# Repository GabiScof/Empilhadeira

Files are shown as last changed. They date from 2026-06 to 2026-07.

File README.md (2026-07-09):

# Empilhadeira Robótica Autônoma

Projeto da disciplina ENG4061 — Projeto Robótica (PUC-Rio, Turma 3VB).

Empilhadeira em escala reduzida que transporta pallets (~15 cm) em ambiente
controlado (corredor 0,80 × 1,60 m com 6 AprilTags). Dois modos de operação:

- **Manual** — o operador dirige por joystick virtual no celular.
- **Autônomo** — o robô navega sozinho entre AprilTags no mapa, executa missão
  pick-and-place ou estaciona em frente a uma tag (dock-to-tag).

O garfo é sempre manual: tem canal de comando independente nos dois modos e
nunca entra na malha autônoma.

Este README é o ponto de entrada do repositório: resume o que foi feito, como
o sistema funciona e aponta para a documentação detalhada de cada parte
(seção [Mapa da documentação](#mapa-da-documentação)).

---

## Estrutura do repositório

```
Empilhadeira/
├── src/                        Monorepo de software (Pi + ESP32 + frontend + docs)
├── Eletrônica/                 Hardware elétrico: esquemáticos, datasheets, caixas, testes
├── Apresentações_&_Relatório/  PDFs entregues (pré-projeto e entrega final)
├── modelagem_3D/               STLs das peças mecânicas (garfo, polias, eixo, carretel, suporte)
├── images/                     Imagens de apoio (folha de AprilTags tag25h9)
├── APRESENTACAO_SPEC.md        Roteiro técnico da apresentação (visão, controle, comunicação)
└── requirements.txt            Dependências Python fixadas para deploy no Pi
```

---

## Arquitetura

Três camadas hierárquicas, cada uma em um processador e linguagem próprios:

```
┌──────────────────────────────────────────────────────────┐
│  FRONTEND — celular (React + Vite, navegador)             │
│  joystick · D-pad · garfo · missão · mapa · arena · dock  │
└──────────▲──────────────────────────┬─────────────────────┘
     (2) telemetria @20Hz      (1) comando
         WebSocket / Wi-Fi            ▼
┌──────────┴───────────────────────────────────────────────┐
│  RASPBERRY PI — alto nível (Python, FastAPI + asyncio)    │
│  3 loops (Vision · Serial · Control) + WS handler          │
│                                                            │
│  AprilTag → EKF 2D → planejador → executor → setpoint     │
└──────────▲──────────────────────────┬─────────────────────┘
     (4) sensores               (3) setpoint
     UART USB 115200, 20 Hz — JSON + CRC8 + \n
                                      ▼
┌──────────┴───────────────────────────────────────────────┐
│  ESP32 — baixo nível, tempo real (C++/Arduino/PlatformIO) │
│  PID por roda ~100 Hz · encoders · MPU-6050 · PWM → L298n │
└───────────────────────────────────────────────────────────┘
```

Há quatro contratos de dados congelados entre as camadas, espelhados em Python
(Pydantic), C++ (ArduinoJson) e TypeScript. Qualquer mudança de contrato
precisa ser aplicada nas três linguagens.
Detalhes: [`src/docs/serial-protocol.md`](src/docs/serial-protocol.md).

---

## Visão

A câmera USB é o único sensor absoluto. Pipeline:

```
Câmera USB (1280×720) → grayscale → pupil-apriltags (tag25h9, PnP)
  ├─ VisionState (tag mais próxima): detectado, id, z_cm, x_cm, pitch_deg
  └─ TagObservations (todas) → correção do EKF 2D [x, y, θ]
```

**Compensação de tilt:** a câmera fica inclinada 30° para baixo (no topo do
trilho do garfo). `pose.py` rotaciona a pose bruta pelo ângulo de tilt antes
de extrair z/x — converte distância no eixo óptico para distância horizontal.

**Convenções de sinal (validadas na bancada em 2026-07-07):**

- **x negado** na fronteira: no OpenCV, x+ significa tag à direita; na
  convenção do projeto, x+ significa tag à esquerda. Sem essa negação o robô
  se afastaria da tag no hardware (em simulação o problema não aparecia porque
  a visão sintética já usava a convenção do projeto).
- **pitch negado**: a câmera real reporta sinal oposto ao do simulador.
- **Offset câmera→garfo** aplicado em z (−10 cm, lente atrás da ponta do
  garfo) e x, para que z_cm represente a distância da ponta do garfo à tag.

**Multi-tag:** `estimate_vision_state` retorna a tag mais próxima para o
controle reativo; `estimate_tag_observations` retorna todas para o EKF.

**Braço de alavanca lente→eixo:** a pose medida é a da lente, mas o EKF estima
o centro do robô. A correção subtrai `LENS_TO_AXLE_FORWARD_CM` (18 cm) na
direção do heading para evitar viés sistemático.

### Calibração

Procedimento: tabuleiro de xadrez OpenCV. Calibração atual: 2026-07-07,
câmera nova remontada com tilt de 30°, a 1280×720. Intrínsecos:
fx=fy=1023,63 · cx=634,08 · cy=377,08, com coeficientes de distorção
completos (erro de reprojeção não registrado). Uma calibração anterior
(câmera antiga, 640×480, 28 fotos com cantos internos 8×5 e quadrado de
3 cm, reprojeção 0,144 px) foi descartada por valores anômalos.

Regra operacional: a resolução de captura precisa ser a mesma da calibração.
Com `REQUIRE_CAMERA_CALIBRATION=1`, o backend não sobe em modo real sem
calibração válida.

### Visão sintética (SIM=1)

FOV 60°, alcance 3–150 cm, ruído gaussiano ±0,2 cm / ±0,5°, com injeção de
falhas (`tag_hidden`, `vision_blur`, `vision_drop`). Os 9/9 cenários de
aproximação foram validados nessa visão sintética antes de existir robô
físico.

---

## Controle

### Malha em cascata (2 níveis, 2 processadores)

```
Pose alvo (mapa)
   ↓
PathPlanner → [FORWARD 1.2m, TURN 90°, ...]
   ↓
SegmentExecutor — malha EXTERNA no Pi @20 Hz
   pose EKF → (v, ω) → (ω_esq, ω_dir) em rad/s
   ↓ setpoint via serial
PID por roda no ESP32 — malha INTERNA @100 Hz
   ω medido (encoder) → duty PWM → motor
```

O Pi não duplica o PID de roda: a malha externa cuida de posição/heading, a
interna de velocidade. A divisão também é de tempo real — o ESP32 garante
determinismo a 100 Hz; o Pi roda a 20 Hz em Python/asyncio.

### Arbitragem do control loop

O `control_loop.py` roda a 20 Hz e decide qual controlador gera o setpoint:

| Condição | Controlador |
|---|---|
| `MANUAL` | Joystick → cinemática diferencial |
| `AUTOMATICO` + missão ativa | Missão → PathPlanner → SegmentExecutor compartilhado |
| `AUTOMATICO` + dock ligado + sem missão | TagDocker (plano e executor próprios) |
| `AUTOMATICO` + dock desligado + sem missão | NavigationController legado (servo contínuo) |
| `PARADO` / sem comando | Rodas zeradas |

O dock está ligado por default (hardcoded `True` desde 2026-07-07) — o caminho
padrão do AUTOMATICO sem missão é o dock, não o navegador legado.

### Cinemática diferencial

`v = y × MAX_LINEAR_SPEED`, `ω = −x × MAX_ANGULAR_SPEED` (x negado: joystick
x+ = direita, mas ω+ = anti-horário). Velocidades de roda:
`w_esq = (v − ωL/2)/r`, `w_dir = (v + ωL/2)/r`.

### PathPlanner

Se o mapa tem grafo de waypoints: A* sobre o grafo, segmentos TURN/FORWARD
entre waypoints. Se não tem: fallback Manhattan (alinha X, depois Y).
Segmentos menores que 0,5 cm são descartados.

### SegmentExecutor

Malha proporcional sobre a pose do EKF:

- `v = K_DIST × distância` (K=1,5, cap 0,30 m/s)
- `ω = K_HEADING × erro_heading` (K=2,5)
- Tolerância de posição: 2 cm; heading: 4° (folga para o piso de ω não oscilar)
- Forward: se o erro de heading passa de 45°, para e gira primeiro (`v = 0`)
- Timeout por segmento: 45 s → FAULT da missão

**Anti-atrito estático (correção de bancada, 2026-07-07):** perto do alvo, a
malha proporcional comanda velocidades pequenas demais para vencer o atrito
estático — o motor recebe duty mas o robô não anda. Pisos: `v ≥ 0,09 m/s`
(acima da zona de stick-slip) e `|ω| ≥ 1,0 rad/s` (skid-steer precisa de
torque). Teto de giro: `ω ≤ 1,6 rad/s` — acima disso as rodas derrapam, a
odometria conta rotação que não houve e o EKF acumula erro.

### Dock-to-tag

Modo que estaciona o robô em frente a uma única tag por segmentos discretos.
O plano é feito uma vez; a execução usa odometria/EKF. Usa a mesma maquinaria
de navegação da missão (PathPlanner + SegmentExecutor), então serve de ensaio
para a parte de navegação dela (a missão ainda envolve o grafo de waypoints e
a máquina de estados, que o dock não exercita).

**Estados:** `SEEKING` (acumula detecções) → `DOCKING` (executa rota) →
`DONE` / `FAULT`

**Planejamento (Manhattan no frame do robô, não do mapa):**

1. Projeta o alvo no frame do robô: `dz` para frente, `dlat` para o lado.
2. Rota: avança `dz` → gira ±90° → avança `|dlat|` → giro final para alinhar.
   Pernas menores que 1 cm são descartadas.

**Estratégias:** `line_of_sight` (default — usa só z/x, não depende de
convenção de yaw) e `tag_normal` (esquadra com a face da tag; usa a convenção
de yaw com offset π, validada na bancada em 2026-07-07).

**EKF suprimido durante DOCKING:** a `vision_loop` não faz correção por tag
enquanto o dock executa, para evitar salto de pose se a tag não estiver
exatamente na posição declarada no mapa.

**Re-planejamento:** quando DONE, se aparece uma tag que exige deslocamento
maior que 0,10 m, replaneja automaticamente.

### Navegação reativa legada (1 tag)

Controlador servo-contínuo sobre a leitura da câmera. Usado quando o dock está
desligado e não há missão. Quatro fases:

| Fase | Comportamento |
|---|---|
| `COARSE_ALIGN` | Entra quando `|pitch| > 45°`. Gira com ω fixo (±2,0 rad/s), sinal travado na entrada. Sai quando `|pitch| < 35°` (histerese). v=0. |
| `APPROACH` | v proporcional à distância (desaceleração `v_max = √(2·a·d)`); ω por bearing proporcional (longe do centro) ou pitch+x (perto). Heading guard: `|pitch| > 30°` → v=0. FOV guard: reduz v perto da borda do FOV. Centering: reduz v quando `|x| > 1,5 cm`. |
| `FACE` | Perto do Zref e lateralmente alinhado, mas com pitch grande. Gira no lugar com ω ampliado (3× KP_PITCH). |
| `RETREAT` | Marcha-ré a −4 cm/s até z ≥ 30 cm, depois volta a APPROACH. |

Detector de oscilação: 5 ou mais trocas de sinal de ω em 10 amostras →
fallback com `allow_stuck_retreat` (se preso, força ré).

### EKF 2D — [x, y, θ]

Estado em metros/radianos. Predição por odometria diferencial + giroscópio
(fusão 70% gyro / 30% odometria para heading). Correção por observação
absoluta de tag: `H = I`, ruído R escalado pela qualidade da detecção, gate de
Mahalanobis 3,0. Exporta elipse de covariância 95% para a UI.

Nota: as constantes de ruído (`EKF_Q_*`, `EKF_R_*`) existem em `config.py`,
mas não estão conectadas ao `ekf.py` — os valores estão hardcoded na classe.

### Kalman IMU (roll/pitch)

Filtro separado para roll e pitch a partir do acelerômetro e giroscópio (via
filterpy). Saída em graus para a telemetria. Não é usado pelo EKF para
heading — esse vem do giroscópio Z diretamente.

### Auto-calibração do giroscópio

Na partida (robô parado ~2–3 s), o `GyroCalibrator`:

1. Usa a gravidade para descobrir qual eixo do MPU aponta para cima.
2. Determina o sinal do yaw (projeção do gyro no vetor "up" de um sensor destro).
3. Estima o bias de taxa-zero.
4. Rastreia drift térmico lento por EMA (α=0,01) após calibrado.

A posição/orientação física do MPU no chassi não importa — o sensor pode ser
remontado sem alterar código. Guard contra MPU morto: se `|accel| < 2,0 m/s²`
(fisicamente impossível com o sensor funcionando), o frame é descartado.

---

## Missão pick-and-place

```
IDLE → LOAD_MAP → DRAW_TARGETS → GO_TO_PICK → AT_PICK
→ GO_TO_PLACE → AT_PLACE → GO_HOME → DONE   (+ FAULT)
```

- Em `AT_PICK` / `AT_PLACE` o robô para, o operador aciona o garfo e clica
  "continuar" (`POST /mission/continue`).
- Prioridade dos alvos: argumento explícito (UI/curl) > default em config
  (L3/R1) > sorteio com seed 42 (hardcoded na state machine).
- Alvos são `position_id` do mapa (ex.: L3, R1).
- A rota é planejada pelo PathPlanner e executada pelo SegmentExecutor
  compartilhado. Na chegada, `mission.notify_route_done()` avança o estado.
- Timeout de segmento → `mission.fault()`.

API REST: `POST /mission/start`, `/mission/continue`, `/mission/reset`,
`GET /mission/state`.

---

## Máquina de estados e segurança

**Modos:** `MANUAL`, `AUTOMATICO`, `PARADO`

**Latch de segurança:** parada por segurança trava e só `acknowledge()`
destrava. Sem o latch, o loop de 20 Hz re-entraria no modo ativo a cada tick.
Durante missão e dock, o control loop chama `acknowledge()` automaticamente e
alimenta `detectado=True` sintético para suprimir o tag-loss (a tag sai do FOV
em curvas normais de 90°).

**Triggers de parada:**

- Tag perdida por mais de 5 frames em AUTOMATICO
- Command watchdog em MANUAL (400 ms sem comando com rodas em movimento)
- `force_stop()` por perda de serial ou desconexão do WebSocket

### Cadeia de watchdogs (5 vigias em 3 processadores)

| Elo que cai | Limite | Ação |
|---|---|---|
| Celular ↔ Pi (Wi-Fi, MANUAL andando) | 400 ms | PARADO com latch, motivo `command_watchdog` |
| WebSocket fecha | imediato | `force_stop` + comando limpo |
| Tag some em AUTOMATICO | 5 frames (~250 ms) | PARADO com latch (suspenso durante missão/dock) |
| UART sem sensores | 5 ciclos (~250 ms) | `force_stop`, motivo `serial_loss` |
| ESP32 sem setpoint | 200 ms | motores zerados + PID reset (local, independe das camadas acima) |

O watchdog do firmware é a última linha de defesa: roda no ESP32 e não depende
de nada acima dele.

---

## Firmware ESP32

**PID por roda a ~100 Hz:** Kp=20, Ki=5, Kd=1, anti-windup com integral
limitada a ±500. PWM LEDC a 20 kHz, 8 bits (0–255).

**Bypass de setpoint zero (correção de bancada, 2026-07-06):** com um encoder
morto (medida=0), o comando de parar tinha erro 0, mas a integral acumulada
segurava o duty no máximo — o robô ignorava o STOP. Correção: setpoint 0 vira
parada incondicional que bypassa o PID e reseta a integral.

**Encoder x4:** interrupções em CHANGE nas duas fases, tabela de transição de
16 entradas (ISR em IRAM). Transição inválida vale 0, o que rejeita bounce por
construção. 1440 contagens/volta.

**IMU MPU-6050 cru:** acelerômetro ±2g e gyro ±250°/s enviados crus (m/s²,
°/s). Toda a fusão fica no Pi (decisão: firmware simples e determinístico;
filtros ficam onde há ponto flutuante e teste fácil). Auto-recuperação: após
~1 s de leituras mortas, o firmware re-envia o wake (`0x6B`).

**Watchdog local:** 200 ms sem setpoint válido → motores zerados + PID
resetado.

**Garfo:** duty fixo (220); a rosca sem-fim segura a carga parada.
Fins-de-curso previstos no código, mas desabilitados (não montados).

Detalhes: [`src/firmware/README.md`](src/firmware/README.md).

---

## Frontend

Três páginas:

- **Operador** (`/`) — joystick, seletor de modo, D-pad, garfo, dock,
  telemetria, missão, alertas de segurança.
- **Demo** (`/demo`) — arena vista de cima (sim ou real via `/world-state`),
  missão, injeção de falhas, reset de pose, export de debug, seletor de mapa.
- **Mapa** (`/map`) — visualização de mapas JSON com tags, waypoints e grafos.

**D-pad (instrumento de teste):** botões que enviam vetores puros — Frente com
ω exatamente 0 (reta), Gira com v exatamente 0 (giro no lugar), em 30/60/100%
da velocidade. Re-envia a cada 100 ms (heartbeat para o watchdog de 400 ms).
Elimina a variabilidade do joystick nos testes de retidão e odometria.

**Arena:** canvas 2D com grid, tags (pick em vermelho, place em verde), robô
(triângulo azul com cone de FOV), elipse do EKF, trilha executada e rota
planejada (segmentos FORWARD em tracejado).

**WebSocket (reconnect + anti-flapping):** backoff exponencial 500 ms → 10 s.
Guard contra sockets órfãos da dupla montagem do React 18 StrictMode.

### Duas topologias de rede

- **Modo DEV:** frontend no Mac (`npm run dev`, porta 5173); backend no Pi;
  `VITE_PI_WS_URL=ws://<IP_DO_PI>:8000/ws` obrigatório.
- **Modo OPERAÇÃO:** `npm run build` no Mac, `rsync dist/` para o Pi; o
  backend serve o SPA na porta 8000 — sem Node/npm no Pi, uma porta só, e o
  WebSocket resolve sozinho para o host da página.

Detalhes: [`src/frontend/README.md`](src/frontend/README.md).

---

## Simulação (sim-to-real)

Toda a lógica do Pi roda idêntica em `SIM=1` e `SIM=0`. A simulação substitui
duas peças de hardware atrás das mesmas interfaces:

| Componente | Real (`SIM=0`) | Simulado (`SIM=1`) |
|---|---|---|
| Câmera | `RealVisionSource` (OpenCV) | `SimVisionSource` (visão sintética, FOV 60°, ruído) |
| ESP32 | `PySerialTransport` (UART) | `FirmwareEmulator` (PID em Python, motor de 1ª ordem, τ=50 ms) |

As interfaces `VisionSource` e `SerialTransport` garantem que não existe
`if SIM` no código de navegação, controle ou missão.

**Injeção de falhas:** `serial_drop` (ESP32 ignora setpoints), `tag_hidden`
(visão retorna vazio), `wheel_slip` (multiplicadores por roda),
`vision_blur/drop` (probabilidade por frame), `encoder_noise`, `gyro_drift`.

**Mundo simulado:** cinemática diferencial com opção de slip por roda, clamp
na arena, trilha de 2000 pontos.

---

## Problemas encontrados e correções

### Hardware (bancada, 2026-07-06 e 2026-07-07)

1. **Canais dos motores trocados na fiação:** o canal A do L298n acionava a
   roda direita e o B a esquerda — as malhas PID ficaram cruzadas (cada PID
   lia um encoder e acionava a outra roda). Sintoma: uma roda saturava e a
   outra parava, alternando de lado entre testes. Corrigido por remapeamento
   em software. Lição: testar sempre um lado por vez (`--w-esq X --w-dir 0`).

2. **Encoder sobrecontando ~420 pulsos/volta:** estava nos GPIOs 34/35, que
   são input-only e sem pull-up interno — a linha flutuando gerava contagem
   por ruído. Refiado para os GPIOs 23/15 com `INPUT_PULLUP`. Na mesma
   mudança, a decodificação passou de x1 para x4 completa com tabela de
   transição.

3. **Robô ignorava STOP com encoder morto:** a integral acumulada segurava o
   duty no máximo. Correção: setpoint 0 vira parada incondicional que bypassa
   o PID.

4. **MPU-6050 dormindo / barramento I2C caindo:** (a) leituras todas zero com
   temp=36,53 °C indicam sensor dormindo (36,53 é o offset da fórmula de
   temperatura com raw=0); (b) todas zero com temp=0 + erro do Wire indicam
   queda do barramento (contato/EMI perto do L298n). Correções: o firmware
   auto-recupera após ~1 s; o GyroCalibrator descarta frames com
   `|accel| < 2 m/s²`.

5. **Gravação falhando ("chip stopped responding"):** um encoder estava
   alimentado pelo GPIO 2, que é pino de strapping de boot do ESP32.

6. **Ganhos de bancada ≠ chão (assumido):** o atrito estático impede a partida
   com comando baixo; a bateria caindo faz o PID saturar antes.

### Lógica (encontrados em simulação)

- AUTOMATICO congelava após 1 comando (control loop desacoplado do frontend)
- PARADO oscilava sem latch de segurança
- Integral do PID não resetava em PARADO
- ZREF=5 cm causava overshoot (ajustado para 15 cm)
- Perda de tag com offset lateral (bearing guard + histerese)
- Omega bang-bang (substituído por proporcional por bearing)
- FACE durava 1–2 ticks (imposto mínimo de 0,5 s)
- Parada falsa a 24–25 cm (dead zone com histerese)

### Convenções de sinal (fronteira sim↔real)

- Joystick x → ω negado (x+ = direita, ω+ = anti-horário)
- Visão x/pitch negados na fronteira (`pose.py`)
- Dock Manhattan calculado no frame do robô, não do mapa (bug de bancada)
- EKF corrige para o centro do robô (lente→eixo = 18 cm)
- Tilt da câmera 30° + offset z = −10 cm

---

## Decisões de projeto

- Arquitetura hierárquica de 3 camadas: Frontend → Pi → ESP32.
- Pi em Python/FastAPI/asyncio. ESP32 em C++/Arduino/PlatformIO.
- Frontend em React + Vite (navegador do celular).
- Frontend ↔ Pi: WebSocket. Pi ↔ ESP32: UART USB, JSON + CRC8.
- Garfo sempre manual — sem atuação autônoma no protocolo serial.
- Monorepo com três apps (`pi/`, `firmware/`, `frontend/`) + `docs/` + `scripts/`.
- Mapas em JSON — arena paramétrica, não hardcoded.
- PID de roda no ESP32 (100 Hz, C++); malha de posição no Pi (20 Hz, Python).
- Toda a fusão sensorial no Pi (firmware simples e determinístico).
- Simulação atrás de interfaces (`VisionSource`, `SerialTransport`), sem `if SIM`.

---

## Hardware

- Raspberry Pi + câmera USB (1280×720)
- ESP32 DevKit V1
- 2× ponte-H L298n (4 canais: 2 rodas + 1 garfo)
- 2× motor Lego NXT 53787 (rodas) com encoder de quadratura (1440 pulsos/volta, x4)
- Motor JGY-370 12 V com rosca sem-fim (garfo)
- IMU MPU-6050 (I2C)
- Alimentação: 3× 18650 em série (12,6 V) + BMS 3S 40A + regulador LM2596 (5,3 V)
- Arena: corredor 0,80 × 1,60 m com 6 AprilTags (tag25h9, 4 cm)
- Mapa: `corredor_6tags_80x160.json` (tags L1–L3 e R1–R3)

A parte elétrica (bateria, BMS, regulador, drivers, esquemáticos, datasheets,
caixas dos eletrônicos) está documentada em
[`Eletrônica/README.md`](Eletrônica/README.md).

---

## Mecânica

A estrutura mecânica da empilhadeira foi desenvolvida com um sistema de elevação baseado em **polia com corda**. Nesse mecanismo, o motor aciona o carretel, que enrola ou desenrola a corda responsável por movimentar o garfo verticalmente. A polia foi utilizada para guiar a corda e permitir que o movimento de subida e descida ocorresse de forma mais controlada.

Além dos componentes comerciais, também foi feita uma **modelagem 3D própria**, armazenada na pasta [`modelagem_3D/`](modelagem_3D/). Essa pasta contém os arquivos STL das peças mecânicas utilizadas no projeto, incluindo:

- `Carretel.stl`
- `Eixo.stl`
- `Garfo.stl`
- `Polia Direita.stl`
- `Polia Esquerda.stl`
- `Suporte.stl`

Na montagem mecânica, foram utilizados os seguintes materiais principais:

- Hastes metálicas de 8 mm de diâmetro;
- Rolamentos lineares LM8UU;
- Polia com rolamento interno de 5 mm de diâmetro;
- Motor worm gear para acionamento do garfo.

A escolha do motor com rosca sem-fim foi importante porque ele permite maior redução de velocidade e ajuda a manter o garfo parado quando o motor não está sendo acionado, evitando que a carga desça sozinha. Dessa forma, a solução mecânica combina peças impressas em 3D, componentes metálicos de guiamento e um sistema simples de polia e corda para realizar o movimento vertical do garfo.

O modelo 3D também pode ser acessado pelo
[Onshape](https://cad.onshape.com/documents/f90b50a5cbad31499728b9c2/w/215a010849009c6ab330cfee/e/5a6f6cd27785eeb6a40e91f8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).

---

## Quick start

### Simulação (sem hardware)

```bash
cd src
python3 -m venv .venv && source .venv/bin/activate
pip install -e ".[dev]"

SIM=1 ./scripts/run_pi.sh           # backend em http://localhost:8000

cd frontend && npm install && npm run dev   # http://localhost:5173/demo
```

### Testes

```bash
python3 -m pytest pi/tests/ -v              # backend (210 testes)
cd frontend && npx vitest run               # frontend (11 testes)
python3 pi/tests/sim_sweep.py               # 9 cenários de aproximação
```

### Deploy no robô real

1. Copie `src/.env.example` para `src/.env` e configure `SIM=0`, a porta
   serial e a câmera.
2. No Pi: `pip install -e .` e `./scripts/run_pi.sh`
3. Frontend (modo operação): `npm run build` no Mac e copie `frontend/dist/`
   para o Pi — o backend serve o SPA em `http://<IP_DO_PI>:8000/`

Guia completo: [`src/docs/hardware-deployment.md`](src/docs/hardware-deployment.md)

---

## Números de referência

| Item | Valor |
|---|---|
| Arena | corredor 0,80 × 1,60 m, 6 tags (L1–L3, R1–R3) |
| AprilTag | família tag25h9, 4 cm |
| Câmera | USB, 1280×720; fx=fy=1023,6 · cx=634,1 · cy=377,1 (calibração 2026-07-07) |
| Tilt da câmera | 30° para baixo; offset z = −10 cm (lente→garfo); lente→eixo = 18 cm |
| Loops do Pi | 3 no startup (Vision · Serial · Control, 20 Hz cada); Telemetria via WS handler por conexão |
| PID firmware | 100 Hz, Kp=20 Ki=5 Kd=1, anti-windup ±500, PWM 20 kHz 8 bits |
| Encoders | quadratura x4, 1440 pulsos/volta |
| EKF | estado [x,y,θ]; heading 70% gyro + 30% odom; gate Mahalanobis 3,0 |
| SegmentExecutor | K_DIST=1,5 · K_HEADING=2,5 · tol. posição 2 cm · tol. heading 4° |
| Anti-atrito | v ≥ 0,09 m/s · \|ω\| ≥ 1,0 rad/s · ω_turn ≤ 1,6 rad/s |
| Serial | UART USB 115200 baud, 20 Hz, JSON + CRC-8/MAXIM + `\n` |
| Watchdogs | comando 400 ms · serial 250 ms · firmware 200 ms · tag-loss 250 ms |
| v_máx medida | 24 cm/s (100 cm em 4,16 s) → config 19 cm/s (80%, folga para PID + bateria) |
| Geometria | roda r=2,7 cm · entre-eixos 15 cm · standoff 15 cm |
| Missão | IDLE→LOAD_MAP→DRAW_TARGETS→GO_TO_PICK→AT_PICK→GO_TO_PLACE→AT_PLACE→GO_HOME→DONE (+FAULT) |

---

## Estrutura do monorepo `src/`

```
src/
├── pi/                    Backend Python (FastAPI + asyncio)
│   ├── app/
│   │   ├── control/       EKF, navegação, planejador, executor, Kalman, dock-to-tag
│   │   ├── mission/       Máquina de estados pick-and-place
│   │   ├── tasks/         3 loops asyncio (visão, serial, controle) + WS handler
│   │   ├── comms/         Protocolo serial (CRC8, framing, transporte)
│   │   ├── vision/        Detector AprilTag, calibração, pose (tilt, offsets)
│   │   ├── hardware/      Interfaces VisionSource / SerialTransport
│   │   ├── sim/           Emulador de firmware, visão sintética, falhas, mundo
│   │   ├── world/         Modelo de mundo, mapas (JSON/Pydantic), robô
│   │   ├── telemetry/     Agregador de telemetria
│   │   ├── config.py      Parâmetros centralizados
│   │   ├── models.py      4 contratos Pydantic
│   │   ├── state.py       Estado compartilhado (lock asyncio)
│   │   └── main.py        Ponto de entrada + rotas REST
│   ├── maps/              Mapas JSON da arena
│   ├── calibracao/        Intrínsecos da câmera (JSON)
│   └── tests/             210 testes pytest
├── firmware/              ESP32 (C++/PlatformIO)
│   └── src/               main, pid, motors, encoders, protocol, config
├── frontend/              React + Vite + Tailwind
│   └── src/
│       ├── pages/         Operador (/), Demo (/demo), Mapa (/map)
│       ├── components/    Joystick, DPad, Arena, Telemetria, Missão, Dock, etc.
│       ├── ws/            useWebSocket (reconnect, anti-flapping)
│       └── types/         contracts.ts (espelho TypeScript)
├── docs/                  Documentação técnica
└── scripts/               Scripts de operação e teste
```

---

## Mapa da documentação

### Ponto de entrada por app

| Documento | Conteúdo |
|---|---|
| [`src/README.md`](src/README.md) | Visão geral do monorepo de software, como rodar e testar |
| [`src/pi/README.md`](src/pi/README.md) | Backend do Raspberry Pi |
| [`src/firmware/README.md`](src/firmware/README.md) | Firmware do ESP32 |
| [`src/frontend/README.md`](src/frontend/README.md) | Frontend React |
| [`Eletrônica/README.md`](Eletrônica/README.md) | Bateria, BMS, regulador, motores, drivers, sensores |

### Conceito e arquitetura

| Documento | Conteúdo |
|---|---|
| [`src/docs/architecture.md`](src/docs/architecture.md) | Arquitetura de 3 camadas, EKF, decisões, parâmetros em aberto |
| [`src/docs/serial-protocol.md`](src/docs/serial-protocol.md) | Os 4 contratos de comunicação (fonte de verdade) |
| [`src/docs/navigation.md`](src/docs/navigation.md) | Planejador, executor, malha em cascata |
| [`src/docs/mission.md`](src/docs/mission.md) | Missão pick-and-place, API REST, garra manual |
| [`src/docs/dock-to-tag.md`](src/docs/dock-to-tag.md) | Aproximação por segmentos a uma tag |
| [`src/docs/maps.md`](src/docs/maps.md) | Formato JSON dos mapas da arena |
| [`src/docs/simulation.md`](src/docs/simulation.md) | Modo SIM=1, injeção de falhas, endpoints `/sim/*` |

### Hardware e operação

| Documento | Conteúdo |
|---|---|
| [`src/docs/hardware-bring-up.md`](src/docs/hardware-bring-up.md) | Pinos, energia, montagem, calibração |
| [`src/docs/hardware-deployment.md`](src/docs/hardware-deployment.md) | Deploy no robô real, passo a passo |
| [`src/docs/hardware-interfaces.md`](src/docs/hardware-interfaces.md) | Interfaces `VisionSource` / `SerialTransport` (SIM↔real) |
| [`src/docs/camera-calibration.md`](src/docs/camera-calibration.md) | Calibração da câmera (xadrez OpenCV) |

### Testes e status

| Documento | Conteúdo |
|---|---|
| [`src/docs/real-robot-test-plan.md`](src/docs/real-robot-test-plan.md) | Plano de testes no hardware em 3 fases |
| [`src/docs/readiness-sim-to-real.md`](src/docs/readiness-sim-to-real.md) | Auditoria de prontidão SIM→real |
| [`src/docs/simulator-to-real.md`](src/docs/simulator-to-real.md) | O que a simulação provou e o que não provou |
| [`src/docs/verification-status.md`](src/docs/verification-status.md) | Testes passando, bugs corrigidos |

### Apresentação e relatórios

| Documento | Conteúdo |
|---|---|
| [`APRESENTACAO_SPEC.md`](APRESENTACAO_SPEC.md) | Roteiro técnico da apresentação (visão, controle, comunicação) |
| `Apresentações_&_Relatório/` | PDFs entregues: relatório pré-projeto, entrega de pré-projeto e entrega final |

---

## Verificação

| Teste | Resultado |
|---|---|
| pytest (backend Pi) | 210 testes — 209 passam, 1 pulado |
| vitest (frontend) | 11/11 passam |
| sim_sweep (9 cenários de aproximação) | 9/9 convergem (parada a 15,0–16,3 cm; offset lateral ≤ 2,4 cm; heading ≤ 3,7°) |
| full_trace (13 cenários) | 12/13 (1 LOST esperado — tag fora do FOV) |
| Bancada 2026-07-07 | encoders x4, motores/sentido, PID, watchdog < 200 ms, CRC e MPU validados |
| Câmera | recalibrada em 2026-07-07 (1280×720, câmera nova) |
| v_máx no chão | cronometrada: 100 cm em 4,16 s = 24 cm/s → config 19 cm/s |

## Status

| Item | Estado |
|---|---|
| Lógica + simulação | Validado (210 pytest + 9/9 sim_sweep) |
| Firmware ESP32 | Gravado e exercitado na bancada (2026-07-06/07) |
| Backend Pi (câmera + serial) | Implementado |
| Calibração da câmera + mapa real | Feito |
| Bancada (encoders, motores, PID, watchdogs) | Validado |
| Dock-to-tag | Implementado, aprovado em teste de unidade |
| Modo operação (Pi serve o frontend) | Funcionando |
| Fase 2 — manual no chão | Pendente |
| Fase 3 — autonomia no chão | Pendente |

## Tech stack

| Camada | Stack |
|---|---|
| Pi | Python 3.11+ · FastAPI · asyncio · OpenCV · pupil-apriltags · filterpy · Pydantic · pyserial-asyncio |
| ESP32 | C++ · Arduino · PlatformIO · ArduinoJson |
| Frontend | React 18 · Vite · Tailwind CSS |

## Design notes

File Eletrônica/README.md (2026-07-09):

# Eletrônica — Empilhadeira Robótica Autônoma

> Extraído do Relatório Pré-Projeto — ENG4061 Projeto Robótica (PUC-Rio, Turma 3VB)

Esta seção documenta a alimentação, o regulador de tensão, os motores/drivers, os
microcontroladores e os sensores utilizados no projeto, além do fluxo geral de
energia e informação do sistema.

---

## Sumário

- [2.1 Bateria e BMS](#21-bateria-e-bms)
- [2.2 Regulador de tensão](#22-regulador-de-tensão)
- [2.3 Motores e drivers](#23-motores-e-drivers)
- [2.4 Microcontroladores](#24-microcontroladores)
- [2.5 Sensores](#25-sensores)
- [2.6 Fluxo do projeto](#26-fluxo-do-projeto)
- [Resumo de componentes](#resumo-de-componentes)
- [Conteúdo da pasta](#conteúdo-da-pasta)

---

## 2.1 Bateria e BMS

O sistema é alimentado por 3 baterias 18650 de íon-lítio em série, cada uma com 4,2 V,
totalizando uma tensão nominal de **12,6 V**. Essa tensão supre motores, microcontroladores e
sensores. As baterias de íon-lítio foram escolhidas pela facilidade de uso, portabilidade e
disponibilidade em laboratório — exigindo atenção ao controle de temperatura, já que são
inflamáveis em condições extremas.

Para gerenciar as baterias com segurança, é utilizado um **BMS (Battery Management System)**,
responsável por:
- Controlar temperatura, carga e descarga das baterias
- Balancear a carga entre as células
- Verificar estado de vida e estado de carga
- (Em versões mais avançadas) transmitir dados das baterias para processamento posterior

**Opção adotada:** BMS 3S 40A — escolhido como opção conservadora frente aos picos de corrente
estimados dos motores sob carga (consumo estimado do sistema entre 10–15 A dependendo do modo
de operação).

---

## 2.2 Regulador de tensão

Como a alimentação de 12,6 V das baterias é inconsistente para os demais componentes, é
utilizado um único regulador de tensão para estabilizar a alimentação e proteger componentes
sensíveis:

| Regulador | Função | Tensão de saída |
|---|---|---|
| **LM2596** | Alimenta todos os periféricos (Raspberry Pi, ESP32, sensores, câmera) | 12V → 5,3V |

> Um único regulador é suficiente porque todos os demais componentes (Raspberry Pi, ESP32,
sensores, câmera) já possuem reguladores de tensão internos próprios, que ajustam os 5,3V de
entrada para o nível exigido por cada um, evitando que queimem.

---

## 2.3 Motores e drivers

| Motor | Uso | Características |
|---|---|---|
| **Lego NXT (id 53787)** | Movimentação (tração) | Torque de 16,7 N·cm · 117 RPM · encoder integrado · controle via PWM (ESP32) |
| **JGY-370-12V (Worm Gear)** | Garfo mecânico (elevação) | Motor DC com caixa de redução sem-fim; dificulta *backdrive* (sustenta carga passivamente quando desenergizado) |

**Driver:** 2× `L298N` (ponte H dupla) — controlam os três motores: um módulo aciona os
dois motores de tração e o outro o motor do garfo, com controle de sentido e PWM por canal.

---

## 2.4 Microcontroladores

O projeto utiliza dois microcontroladores em uma arquitetura hierárquica:

- **Raspberry Pi** — controle de alto nível: processamento das AprilTags (visão computacional),
máquina de estados de movimentação, lei de navegação autônoma e agregação de telemetria.
- **ESP32** — controle de baixo nível: geração de PWM, malhas fechadas locais (PID) dos motores,
leitura de sensores embarcados (MPU-6050, encoders) e comunicação serial com o Raspberry Pi.

> O ESP32 foi escolhido por sua facilidade em controlar motores com precisão em tempo real —
algo que o Raspberry Pi, rodando um SO Linux convencional, não garante nativamente.

---

## 2.5 Sensores

- **MPU-6050** — acelerômetro + giroscópio (a temperatura integrada não entra na fusão;
viaja na telemetria e serve para diagnóstico do sensor). Os dados são lidos pelo ESP32 via
I²C e enviados crus ao Raspberry Pi, onde um **filtro de Kalman** estima roll/pitch e o
giroscópio Z entra direto na fusão de heading do EKF.
- **Encoders integrados** (motor Lego) — usados para calcular RPM e realimentar a malha PID de
controle de velocidade.
- **Câmera** — utilizada para detecção de AprilTags via visão computacional (OpenCV + pupil-apriltags).

---

## 2.6 Fluxo do projeto

A eletrônica funciona como um fluxo contínuo de energia e informação:

1. A energia das baterias é condicionada e dividida em dois caminhos: um direto aos motores, e
outro regulado (LM2596, 5,3V) para os microcontroladores/sensores.
2. Sensores e encoders alimentam o ESP32, que repassa os dados ao Raspberry Pi via serial (UART).
3. O Raspberry Pi processa a informação (visão computacional + telemetria) e retorna *setpoints*
ao ESP32.
4. O ESP32 converte os *setpoints* em movimento físico nos motores.
5. O Raspberry Pi transmite os dados consolidados ao dispositivo do operador (frontend), que
pode enviar novos comandos, fechando o ciclo.

```
Baterias (12,6V) ──┬──► Motores (tração + garfo)
                    └──► Regulador LM2596 (5,3V) ──► RPi / ESP32 / Sensores / Câmera

Sensores/Encoders ──► ESP32 ──UART──► Raspberry Pi ──WebSocket──► Frontend (operador)
                       ▲                                              │
                       └──────────────── comandos/setpoints ──────────┘
```

---

## Resumo de componentes

| Categoria | Componente | Observação |
|---|---|---|
| Fonte | 3× baterias 18650 (íon-lítio) | Série · 12,6 V nominal |
| Proteção | BMS 3S 40A | Balanceamento e proteção de carga/descarga |
| Regulador | LM2596 | 12V → 5,3V (único, alimenta todos os periféricos) |
| Driver | 2× L298N (Ponte H dupla) | Um módulo para os 2 motores de tração, outro para o garfo |
| Motor | Lego NXT 53787 ×2 | Tração |
| Motor | JGY-370-12V (Worm Gear) | Garfo mecânico |
| Microcontrolador | Raspberry Pi | Alto nível — visão computacional, navegação, telemetria |
| Microcontrolador | ESP32 | Baixo nível — PWM, PID, leitura de sensores |
| Sensor | MPU-6050 | IMU (acelerômetro + giroscópio; termômetro só para diagnóstico) |
| Sensor | Câmera | Detecção de AprilTags |

---

## Conteúdo da pasta

| Item | Descrição |
|---|---|
| `Circuito_elétrico_final.pdf` / `Circuito_elétrico_V1.pdf` | Esquemas elétricos (versão final e V1) |
| `Esquemática_elétrica/` | Projeto KiCad do esquema elétrico |
| `Datasheets/` | Datasheets dos componentes (ESP32, L298, LM2596, MPU-6000/6050, AMS1117, MP2307) |
| `Caixa_eletrônicos/` | Caixas dos eletrônicos — V1 e V2 (STEP/Parasolid + fotos) |
| `Testes_eletronica.ino` | Sketch de referência dos testes de bancada da eletrônica |
| `Fotos_Vídeos/` | Fotos e vídeos da montagem |
| `Calculo de corrente.txt` / `Lista de Compras.txt` | Dimensionamento de corrente e lista de compras |

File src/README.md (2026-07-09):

# Empilhadeira Robótica Autônoma

Empilhadeira em escala reduzida com navegação autônoma por AprilTag, missão
pick-and-place e telemetria em tempo real.

> Estado atual: lógica implementada e validada em simulação (`SIM=1`).
> Pronta para bring-up no hardware real — ver
> [`docs/hardware-deployment.md`](docs/hardware-deployment.md).

## Arquitetura — 3 camadas

```
┌──────────────────────────────────────────────────────┐
│  Frontend (celular) — React + Vite                    │
│  joystick · telemetria · missão · mapa · garfo        │
└───────────────▲──────────────────────┬────────────────┘
        (2) telemetria @20Hz    (1) comando
            WebSocket / Wi-Fi          ▼
┌───────────────┴────────────────────────────────────────┐
│  Raspberry Pi — Python (FastAPI + asyncio)              │
│  Vision · Serial · Control Loop (3 loops no startup)   │
│  + WebSocket handler por conexão                       │
│  EKF 2D · planejador · missão · dock · nav legada     │
└───────────────▲──────────────────────┬─────────────────┘
        (4) sensores            (3) setpoint
        UART USB 115200, 20 Hz · JSON+CRC8+\n
                                       ▼
┌───────────────┴─────────────────────────────────────────┐
│  ESP32 — C++ (Arduino, PlatformIO)                       │
│  PID por roda ~100 Hz · encoders · MPU · PWM → L298n    │
└─────────────────────────────────────────────────────────┘
```

Detalhes em [`docs/architecture.md`](docs/architecture.md).

## Apps

| Pasta | Camada | README |
|---|---|---|
| [`pi/`](pi/) | Raspberry Pi (Python) | [pi/README.md](pi/README.md) |
| [`firmware/`](firmware/) | ESP32 (C++) | [firmware/README.md](firmware/README.md) |
| [`frontend/`](frontend/) | Celular (React) | [frontend/README.md](frontend/README.md) |

## Como rodar

```bash
# Instalar
python3 -m venv .venv && source .venv/bin/activate
pip install -e ".[dev]"
cp .env.example .env   # ajustar conforme ambiente (nota: MAP= no .env NÃO tem efeito; mapa padrão é hardcoded)

# Simulação (sem hardware)
SIM=1 ./scripts/run_pi.sh

# Hardware real
SIM=0 ./scripts/run_pi.sh

# Frontend
cd frontend && npm install && npm run dev

# Testes completos
python3 -m pytest pi/tests/ -v
bash scripts/verify.sh
```

> O pacote `app` vive em `pi/app`. O script `run_pi.sh` já roda de dentro de `pi/`.
> Alternativa manual: `SIM=1 uvicorn app.main:create_app --factory --app-dir pi`.

## Documentação

| Documento | Conteúdo |
|---|---|
| [readiness-sim-to-real.md](docs/readiness-sim-to-real.md) | Auditoria sim→real — Pi, ESP, filtros, interfaces, bloqueantes |
| [simulator-to-real.md](docs/simulator-to-real.md) | O que a simulação cobre e o que transferimos |
| [hardware-deployment.md](docs/hardware-deployment.md) | Passo a passo no robô real |
| [verification-status.md](docs/verification-status.md) | Testes passando, bugs corrigidos, sim_sweep |
| [hardware-interfaces.md](docs/hardware-interfaces.md) | Encaixes SIM↔real (`VisionSource`, `SerialTransport`) |
| [hardware-bring-up.md](docs/hardware-bring-up.md) | Pinos, energia, fiação, calibração |
| [serial-protocol.md](docs/serial-protocol.md) | Contratos serial (4 mensagens) |
| [architecture.md](docs/architecture.md) | Decisões, parâmetros em aberto |
| [navigation.md](docs/navigation.md) | Planejador, executor, APPROACH/FACE/RETREAT |
| [mission.md](docs/mission.md) | Missão pick-and-place |
| [dock-to-tag.md](docs/dock-to-tag.md) | Aproximação por segmentos a 1 tag (`DOCK_TO_TAG_ENABLED`, ligado por default) |
| [maps.md](docs/maps.md) | Formato JSON dos mapas |
| [simulation.md](docs/simulation.md) | Modo SIM=1, falhas, APIs `/sim/*` |
| [camera-calibration.md](docs/camera-calibration.md) | Calibração xadrez |

## Verificação (2026-07-08)

| Check | Resultado |
|---|---|
| pytest | 210 testes (209 passam, 1 pulado) |
| frontend vitest | 11/11 |
| sim_sweep | 9/9 convergem |
| full_trace | 12/13 (1 LOST esperado — FOV) |

## Parâmetros em aberto

Valores provisórios em `pi/app/config.py` e `firmware/src/config.h`, marcados
`TODO(equipe)`. Lista completa em
[`docs/architecture.md#parâmetros-em-aberto`](docs/architecture.md#parâmetros-em-aberto)
e checklist de medição em [`docs/hardware-deployment.md`](docs/hardware-deployment.md).

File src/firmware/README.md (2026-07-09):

# Firmware ESP32 — Empilhadeira Robótica

Controle de baixo nível em tempo real: PID por roda, acionamento PWM/L298n, leitura de
encoders por interrupção, MPU-6050, garfo com fim-de-curso e protocolo serial JSON+CRC8.

## Sumário

1. [Arquitetura do Firmware](#1-arquitetura-do-firmware)
2. [Mapa de Pinos (GPIO)](#2-mapa-de-pinos-gpio)
3. [Fiação Detalhada](#3-fiação-detalhada)
4. [Constantes e Calibração](#4-constantes-e-calibração)
5. [Comportamento Esperado](#5-comportamento-esperado)
6. [Como Compilar e Gravar](#6-como-compilar-e-gravar)
7. [Procedimentos de Teste](#7-procedimentos-de-teste)
8. [Troubleshooting](#8-troubleshooting)
9. [Decisões Pendentes (TODO)](#9-decisões-pendentes-todo)

---

## 1. Arquitetura do Firmware

```
┌──────────────────────────────────────────────────────┐
│                    loop()                             │
│                                                      │
│  ┌─────────────────────┐  ┌────────────────────────┐ │
│  │  Serial RX (contínuo)│  │ Watchdog (200 ms)      │ │
│  │  SetpointFrameDecoder│  │ → motorsStop() se cair │ │
│  └─────────┬───────────┘  └───────────┬────────────┘ │
│            │                          │              │
│  ┌─────────▼──────────────────────────▼──────────┐   │
│  │  PID Loop ~100 Hz (cada 10 ms)                │   │
│  │  1. encoderReadEsq/Dir(dt) → ω medido         │   │
│  │  2. pid.update(medido, dt) → esforço u        │   │
│  │  3. motorSetWheel(u) → PWM/L298n              │   │
│  │  4. motorSetFork(cmd) → com fim-de-curso      │   │
│  └───────────────────────────────────────────────┘   │
│                                                      │
│  ┌───────────────────────────────────────────────┐   │
│  │  Serial TX ~20 Hz (cada 50 ms)                │   │
│  │  1. readMpu(sensors) → I2C burst read 14B     │   │
│  │  2. encodeSensors() → JSON+CRC8+\n            │   │
│  │  3. Serial.write(frame)                       │   │
│  └───────────────────────────────────────────────┘   │
└──────────────────────────────────────────────────────┘
```

- **Dual-cadence non-blocking**: `millis()` controla os intervalos, sem `delay()`.
- **PID por roda**: Kp + Ki + Kd com anti-windup (clamping integral a ±500).
- **Watchdog de setpoint**: 200 ms sem mensagem do Pi → motores zerados.
- **Garfo com fim-de-curso**: corte local instantâneo (~100 Hz), sem depender do Pi.

---

## 2. Mapa de Pinos (GPIO)

### Tabela completa

Alinhado 1:1 com `Testes_eletronica.ino` (fonte da verdade da placa real).
Os nomes entre colchetes são os defines equivalentes naquele firmware de teste.

| Função | GPIO | Dir | Destino no Hardware | Observação |
|---|---|---|---|---|
| Motor Esq IN1 | 27 | OUTPUT  | L298n #1 IN3 (canal B) | [era M3_IN1] canais trocados na fiação — ver nota abaixo |
| Motor Esq IN2 | 26 | OUTPUT  | L298n #1 IN4 (canal B) | [era M3_IN2] |
| Motor Esq PWM | 25 | OUTPUT  | L298n #1 ENB (canal B) | [era M3_EN] LEDC ch0, 20 kHz, 8 bits |
| Motor Dir IN1 | 12 | OUTPUT  | L298n #1 IN1 (canal A) | [era M2_IN1] strapping — LOW no boot, sem pull-up externo |
| Motor Dir IN2 | 14 | OUTPUT  | L298n #1 IN2 (canal A) | [era M2_IN2] |
| Motor Dir PWM | 13 | OUTPUT  | L298n #1 ENA (canal A) | [era M2_EN] LEDC ch1, 20 kHz, 8 bits |
| Fork IN1 | 18 | OUTPUT  | L298n #2 IN1 | [M1_IN1] |
| Fork IN2 | 19 | OUTPUT  | L298n #2 IN2 | [M1_IN2] |
| Fork PWM | 5 | OUTPUT  | L298n #2 ENA | [M1_EN] LEDC ch2, 20 kHz, 8 bits |
| Encoder Esq A | 23 | INPUT↑  | NXT 53787 encoder fase A | Interrupção CHANGE (x4) — refiado 2026-07-06 (era 34) |
| Encoder Esq B | 15 | INPUT↑  | NXT 53787 encoder fase B | Interrupção CHANGE (x4) — refiado 2026-07-06 (era 35); strapping (MTDO), ver §2 |
| Encoder Dir A | 32 | INPUT↑  | NXT 53787 encoder fase A | [ENC1_A] Interrupção CHANGE (x4) |
| Encoder Dir B | 33 | INPUT↑  | NXT 53787 encoder fase B | [ENC1_B] Interrupção CHANGE (x4) |
| Fork Limit Top | -1 | — | (chave não montada) | Desabilitado — nunca bloqueia |
| Fork Limit Bottom | -1 | — | (chave não montada) | Desabilitado — nunca bloqueia |
| Enc Power VCC | 2 | OUTPUT  | Encoder "VCC" (3,3 V pelo GPIO) | `PIN_ENC_POWER_VCC` — `encodersBegin()` seta HIGH; limite ~40 mA/GPIO |
| Enc Power GND | 4 | OUTPUT  | Encoder GND | `PIN_ENC_POWER_GND` — `encodersBegin()` seta LOW |
| I2C SDA | 21 | I2C | MPU-6050 SDA | Padrão ESP32 |
| I2C SCL | 22 | I2C | MPU-6050 SCL | Padrão ESP32 |

> **Canais dos motores (conferido na bancada 2026-07-06):** na fiação real o
> canal A do L298n (12/14/13) aciona a roda direita e o canal B (27/26/25)
> a esquerda — o inverso do rótulo M2/M3 do `Testes_eletronica.ino`.
> Remapeado por software no `config.h` (`PIN_MOTOR_ESQ_*`=27/26/25 com
> `MOTOR_ESQ_INV=false`; `PIN_MOTOR_DIR_*`=12/14/13 com `MOTOR_DIR_INV=true`),
> validado com `bench_setpoint` um lado por vez.

`INPUT↑` = INPUT_PULLUP (resistor interno de ~45 kΩ). Todos os pinos de
encoder atuais (23/15 e 32/33) têm pull-up interno — nenhum pull-up externo
é necessário. (Refiado 2026-07-06: o encoder esquerdo estava em 34/35,
input-only e sem pull-up interno, e sobrecontava ~420 pulsos/volta por ruído
nas bordas; foi movido para 23/15.)

### GPIOs com cuidado especial

| GPIO | Motivo |
|---|---|
| 0 | Strapping pin (flash mode se LOW no boot) — não usado |
| 2 | Strapping pin. Usado como "VCC" do encoder (`PIN_ENC_POWER_VCC`, OUTPUT HIGH) e aciona o LED onboard (acende junto — normal). Na gravação precisa estar LOW/solto; a carga do encoder normalmente puxa para baixo — se a gravação falhar, desconectar o fio do GPIO 2 |
| 6-11 | Conectados ao flash SPI interno — nunca usar |
| 12 | Strapping (tensão do flash). Usado como DIR IN1 (canal A; era rotulado ESQ até 2026-07-06) — funciona porque IN1 idle=LOW; não adicionar pull-up externo |
| 15 | Strapping (MTDO). Usado como Encoder Esq B — se LOW no boot, apenas silencia as mensagens de boot da ROM; inofensivo |
| 34-39 | Input-only sem pull-up interno. 34/35 estão livres (refiado 2026-07-06 — o encoder esquerdo saiu deles); se reutilizar, lembrar do pull-up externo |

---

## 3. Fiação Detalhada

### 3.1 L298n #1 (rodas)

```
ESP32 GPIO 12 ──── L298n IN1 (canal A)   ← strapping: sem pull-up externo
ESP32 GPIO 14 ──── L298n IN2 (canal A)
ESP32 GPIO 13 ──── L298n ENA (canal A)   ← remover jumper ENA
ESP32 GPIO 27 ──── L298n IN3 (canal B)
ESP32 GPIO 26 ──── L298n IN4 (canal B)
ESP32 GPIO 25 ──── L298n ENB (canal B)   ← remover jumper ENB

L298n VCC (12V)  ── Fonte 12V
L298n GND        ── GND comum (ESP32 + fonte)
L298n 5V out     ── não usar para alimentar ESP32 (usar USB ou reg. externo)

Motor Dir (+/-) ─── L298n OUT1/OUT2 (canal A)
Motor Esq (+/-) ─── L298n OUT3/OUT4 (canal B)
```

> **Conferido na bancada 2026-07-06:** o canal A aciona a roda direita e o
> canal B a esquerda (fiação real, inverso do rótulo M2/M3). O `config.h` já
> remapeia por software — não trocar fios sem atualizar o mapa de pinos.

Remover os jumpers de ENA e ENB do módulo L298n. Esses jumpers forçam 5V
constante no enable, desabilitando o controle PWM. Com o jumper removido,
o pino ENA/ENB fica livre para receber o sinal PWM do ESP32.

### 3.2 L298n #2 (garfo)

```
ESP32 GPIO 18 ──── L298n #2 IN1
ESP32 GPIO 19 ──── L298n #2 IN2
ESP32 GPIO  5 ──── L298n #2 ENA          ← remover jumper ENA

Motor Garfo (+/-) ── L298n #2 OUT1/OUT2
```

Alternativa: driver menor (L9110S, TB6612) se o garfo precisar de menos corrente.

### 3.3 Encoders (Lego NXT 53787)

```
Motor NXT (conector 6 pinos):
  Pin 1 (branco) ─── 5V (ou 3.3V — verificar)
  Pin 2 (preto)  ─── GND
  Pin 5 (amarelo)─── ESP32 GPIO 23 (Esq A) / GPIO 32 (Dir A)
  Pin 6 (azul)   ─── ESP32 GPIO 15 (Esq B) / GPIO 33 (Dir B)
```

> **Refiado 2026-07-06**: o encoder esquerdo estava em GPIO 34/35 (input-only,
> sem pull-up interno) e sobrecontava por ruído nas bordas. Foi movido para
> 23/15, que têm pull-up interno — o `INPUT_PULLUP` do `encoders.cpp` vale e
> nenhum pull-up externo é necessário. GPIO 34/35 ficaram livres.

> **Nota**: o encoder do NXT opera a 5V pela especificação original. Se o sinal
> de saída for 5V (push-pull), pode ser necessário um divisor resistivo
> (1k + 2k) ou level shifter para proteger o ESP32 (máximo 3.3V nos GPIOs).
> Verificar com multímetro antes de conectar.

### 3.4 MPU-6050

```
MPU VCC ─── 3.3V do ESP32
MPU GND ─── GND
MPU SDA ─── ESP32 GPIO 21
MPU SCL ─── ESP32 GPIO 22
MPU AD0 ─── GND (endereço 0x68)
```

### 3.5 Fim-de-curso do garfo

Estado atual: desabilitado (`PIN_FORK_LIMIT_TOP/BOTTOM = -1` em `config.h`).
As chaves não estão montadas no robô. `motors.cpp` pula o `pinMode` e
`forkAtTopLimit()`/`forkAtBottomLimit()` retornam sempre `false` — o motor do
garfo nunca é bloqueado por limite. O operador deve soltar o botão antes do
fim do curso mecânico (o worm gear segura a posição).

Quando as chaves forem instaladas (fiação de referência):

```
Micro switch NO (topo):
  Terminal C (comum)  ─── GND
  Terminal NO         ─── ESP32 GPIO livre (ex.: 15)

Micro switch NO (base):
  Terminal C (comum)  ─── GND
  Terminal NO         ─── ESP32 GPIO livre (ex.: 4)
```

> GPIO 5 não está mais disponível para fim-de-curso — é o PWM do garfo.
> Definir os novos GPIOs em `config.h` e regravar.

Funcionamento: INPUT_PULLUP mantém o pino HIGH. Quando o garfo atinge o limite,
o switch fecha e puxa o pino para LOW. O firmware detecta LOW = acionado e bloqueia
o motor naquele sentido.

Se os switches forem NC (Normally Closed), trocar `FORK_LIMIT_ACTIVE_LEVEL` para
`HIGH` em `config.h`.

---

## 4. Constantes e Calibração

### 4.1 Valores definidos (prontos para uso)

| Constante | Valor  | Unidade | Justificativa |
|---|---|---|---|
| `SERIAL_BAUDRATE` | 115200 | baud | Decisão fechada (115200) |
| `SERIAL_HZ` | 20 | Hz | Taxa de troca serial |
| `PID_HZ` | 100 | Hz | Malha de controle |
| `SETPOINT_TIMEOUT_MS`  | 200 | ms | 4 mensagens perdidas @ 20 Hz |
| `LEDC_FREQ_HZ` | 20000  | Hz | Acima da faixa audível |
| `LEDC_RESOLUTION_BITS` | 8 | bits | 256 níveis (0-255) |
| `ENCODER_PPR` | 1440 | contagens | Lego NXT 53787: 360 ciclos de quadratura/volta × 4 (decodificação x4) |
| `FORK_DUTY` | 220 | 0-255 | ~86% — subiu de 180 na bancada 2026-07-06/07 p/ levantar com carga |
| `FORK_LIMIT_ACTIVE_LEVEL` | LOW | - | Switch NO + pullup |
| `MPU6050_ADDR` | 0x68 | - | AD0=GND (padrão) |

### 4.2 Ganhos PID (requerem ajuste)

| Ganho | Valor Inicial | Para que serve |
|---|---|---|
| `PID_KP_*`  | 20.0 | Resposta proporcional ao erro |
| `PID_KI_*`  | 5.0 | Elimina erro de regime permanente |
| `PID_KD_*`  | 1.0 | Amortece oscilações |
| `PID_INTEGRAL_LIMIT` | 500.0 | Anti-windup: limita acúmulo integral  |

**Procedimento de sintonia (Ziegler-Nichols simplificado):**

1. Zerar Ki e Kd em `config.h`.
2. Subir Kp gradualmente (10 → 20 → 30 → ...) até o motor oscilar visivelmente
   em torno do setpoint. Esse valor é o ganho crítico Ku.
3. Medir o período da oscilação Tu (com cronômetro ou observando a telemetria).
4. Calcular: Kp = 0.6 × Ku, Ki = 2 × Kp / Tu, Kd = Kp × Tu / 8.
5. Gravar e testar. Ajustar empiricamente (±20%) até suave.

### 4.3 Coisas para verificar antes de ligar

- [ ] Tensão do encoder NXT (5V push-pull? → precisa divisor/level shifter)
- [ ] Sentido de rotação dos motores (se invertido, trocar IN1↔IN2 em `config.h`)
- [ ] ENCODER_PPR correto (girar eixo 1 volta completa → deve ler ~1440 contagens; 10 voltas → ~14400)
- [ ] Switches de fim-de-curso: apertar manualmente e verificar no Serial Monitor
- [ ] MPU-6050 respondendo (I2C scan: `Wire.beginTransmission(0x68)`)
- [ ] Jumpers ENA/ENB do L298n removidos

---

## 5. Comportamento Esperado

### 5.1 Boot (power-on ou reset)

1. `Serial.begin(115200)` — UART pronta.
2. `motorsBegin()` — LEDC configurado, fim-de-curso inicializados, motores zerados.
3. `encodersBegin()` — ISRs ativadas, contadores zerados.
4. `Wire.begin(21, 22)` — I2C inicializado.
5. MPU-6050 acordado (PWR_MGMT_1 = 0x00), aguarda 50 ms para estabilização.
6. Loop principal inicia. `setpointValid = false` → motores parados.
7. ESP32 envia sensores a 20 Hz pela serial (encoders zerados, MPU lendo).

### 5.2 Pi conecta e envia setpoints

1. Frame JSON+CRC8+\n chega na UART → `SetpointFrameDecoder` decodifica.
2. `setpointValid = true`, PID ativado, motores respondem.
3. Telemetria (sensores) flui a 20 Hz de volta para o Pi.

### 5.3 Operação do garfo

- Operador pressiona "subir" no app → Pi envia `"garfo": "subir"` → motor do garfo
  aciona com duty 220 (`FORK_DUTY`) no sentido de subida.
- Garfo atinge o topo → switch fecha → `forkAtTopLimit()` retorna true → motor para
  no próximo ciclo PID (~10 ms). **No firmware atual, os pinos de limite estão
  desabilitados (`PIN_FORK_LIMIT_TOP/BOTTOM = -1`) — `forkAtTopLimit/Bottom()`
  sempre retornam false. Switches não montados.**
- Operador solta o botão → Pi envia `"garfo": "parar"` → motor fica parado.
  O worm gear impede que a carga desça por gravidade.

### 5.4 Perda de comunicação serial

- Pi desconecta (USB solto, crash, etc.).
- Nenhum setpoint novo por 200 ms.
- Watchdog dispara: `motorsStop()` + PID reset.
- ESP32 continua enviando sensores (para diagnóstico quando reconectar).
- Pi reconecta → envia setpoint → `setpointValid = true` → operação retoma.

### 5.5 Reset do ESP32

- Motores param imediatamente (LEDC reseta).
- Setup() roda novamente (sequência do §5.1).
- Sem setpoint → motores parados até o Pi enviar novo comando.

---

## 6. Como Compilar e Gravar

### Pré-requisitos

```bash
pip install platformio    # ou: brew install platformio
```

### Compilar

```bash
cd src/firmware
pio run
```

O PlatformIO baixa automaticamente o toolchain e as libs (ArduinoJson) na primeira vez.

### Gravar no ESP32

```bash
pio run --target upload
```

Se o ESP32 não for detectado, verificar:
- Cabo USB é de dados (não só carregamento).
- Driver CP2102/CH340 instalado.
- Porta correta: `pio device list` para ver portas disponíveis.

### Monitor Serial

```bash
pio device monitor
```

Mostra os frames de sensores que o ESP32 envia a 20 Hz. Exemplo:

```
{"enc":{"esq":0.00,"dir":0.00},"mpu":{"ax":0.12,"ay":-0.03,"az":-10.95,"gx":0.01,"gy":-0.02,"gz":0.00,"temp_c":25.4},"bms":null}*a3
```

> Parado, espere `|az| ≈ 9.8–11`. Neste chassi o MPU está montado com o
> eixo z para baixo, então `az` sai negativo (~-11) — comportamento esperado;
> o `GyroCalibrator` do Pi detecta eixo e sinal automaticamente.

### Atalho: compilar + gravar + monitor

```bash
pio run --target upload && pio device monitor
```

Ou usar o script:

```bash
cd src && bash scripts/flash_firmware.sh
```

---

## 7. Procedimentos de Teste

### Teste 1: Compilação limpa

```bash
cd src/firmware && pio run
```

**Esperado**: `SUCCESS` sem warnings (exceto eventuais warnings do ArduinoJson).

### Teste 2: Serial + MPU-6050

1. Gravar firmware, abrir monitor serial.
2. Sem nenhum motor ou encoder conectado.
3. **Esperado**: frames JSON a 20 Hz com `enc.esq=0, enc.dir=0` e valores de MPU.
4. Inclinar o MPU-6050 → `ax/ay/az` mudam proporcionalmente.
5. `gx/gy/gz` devem estar próximos de zero quando parado.
6. Se tudo zero no MPU: verificar fiação I2C e endereço (ver §8).

### Teste 3: Encoders

1. Sem o Pi — enviar manualmente pelo monitor serial um setpoint:

   ```
   {"w_esq":0,"w_dir":0,"garfo":"parar"}*XX\n
   ```

   (Calcular o CRC correto ou desabilitar temporariamente a validação para teste.)

2. Girar o eixo do motor à mão → observar `enc.esq` ou `enc.dir` mudando.
3. Girar em ambos os sentidos → verificar que o sinal inverte.
4. Uma revolução completa = ~1440 contagens (decodificação x4; verificar no monitor).

### Teste 4: Fim-de-curso do garfo

> Só se aplica quando as chaves forem montadas — hoje
> `PIN_FORK_LIMIT_TOP/BOTTOM = -1` (desabilitadas, ver §3.5).

1. Abrir Serial Monitor.
2. Apertar manualmente o switch do topo → observar se o garfo para de subir.
3. Soltar → garfo pode subir novamente.
4. Repetir para o switch da base.
5. Se não funcionar: verificar fiação (C→GND, NO→GPIO) e `FORK_LIMIT_ACTIVE_LEVEL`.

### Teste 5: Direção dos motores

1. Enviar setpoint com `w_esq = 3.0, w_dir = 0.0` → somente a roda esquerda
   gira, para frente. Se a roda direita girar, os canais A/B estão trocados em
   relação ao mapa de pinos (caso da placa real, corrigido por software em
   2026-07-06 — ver §2).
2. Se girar para trás: inverter o `MOTOR_ESQ_INV` em `config.h`.
3. Repetir para roda direita (`w_esq = 0.0, w_dir = 3.0`).
4. Enviar `w_esq = 3.0, w_dir = 3.0` → robô anda para frente em linha reta.

> Validar sempre um lado por vez. Com os canais trocados e as malhas PID
> cruzadas, o teste conjunto mascara o problema: uma roda satura no máximo, a
> outra morre, e o lado afetado muda aleatoriamente entre execuções.

### Teste 6: PID tuning

1. Definir Ki=0, Kd=0 em `config.h`. Compilar e gravar.
2. Enviar setpoint fixo (ex: `w_esq = 5.0`).
3. Observar a velocidade medida no monitor → aumentar Kp até oscilar.
4. Aplicar Ziegler-Nichols (§4.2).
5. Testar com rampas (0→5→0 rad/s) e observar overshoots.

### Teste 7: Garfo com carga

1. Colocar o pallet no garfo.
2. Comandar "subir" → garfo sobe com a carga?
   - Sim: `FORK_DUTY = 220` está adequado (valor da bancada 2026-07-06/07;
     era 180 e não levantava com carga).
   - Não sobe: aumentar para 240 ou 255.
   - Sobe muito rápido/brusco: diminuir gradualmente.
3. Parar → a carga se mantém? (O worm gear deve segurar.)
4. Descer → desce suavemente?

### Teste 8: Integração com o Pi

1. Subir o backend do Pi (`SIM=0 ./scripts/run_pi.sh` a partir de `src/`).
2. Pi começa a enviar setpoints a 20 Hz.
3. ESP32 responde com sensores a 20 Hz.
4. No app (frontend): mover o joystick → rodas respondem.
5. Comandar garfo subir/descer → garfo responde.
6. Puxar o cabo USB → watchdog para os motores em <200 ms.
7. Reconectar → operação retoma.

---

## 8. Troubleshooting

### Erro de compilação: `ledcSetup was not declared`

**Causa**: `espressif32` versão 7.x+ usa Arduino Core 3.x com API LEDC diferente.
**Solução**: O `platformio.ini` já está pinado em `espressif32@^6.0.0`. Se o erro
persistir, forçar:

```ini
platform = espressif32@6.9.0
```

### MPU-6050 retorna zeros

- Verificar fiação SDA (21) e SCL (22).
- Verificar se AD0 está em GND (endereço 0x68).
- Teste I2C:

```cpp
Wire.beginTransmission(0x68);
byte error = Wire.endTransmission();
Serial.println(error);  // 0 = OK, 2 = NACK
```

### Motor gira no sentido errado

Inverter o `MOTOR_*_INV` (ou trocar IN1 ↔ IN2) em `config.h` para o motor
afetado. Recompilar e gravar.

### Uma roda satura no máximo e a outra morre (lado muda entre execuções)

Sintoma típico de canais A/B trocados (mapa de pinos não bate com a
fiação): cada PID lê o encoder de uma roda mas aciona o motor da outra — as
malhas cruzadas divergem. Foi o caso da placa real, corrigido por software no
`config.h` em 2026-07-06. Diagnóstico: comandar um lado por vez
(`--w-esq X --w-dir 0`) e conferir qual roda gira; o teste conjunto mascara
o problema.

### Encoder lê zero mesmo com motor girando

- Verificar fiação dos pinos A e B.
- Verificar se o encoder opera a 3.3V ou precisa de level shifter.
- Testar com `digitalRead()` direto no pin do encoder.

### PID oscila/vibra

- Reduzir Kp em 30-50%.
- Aumentar Kd levemente.
- Verificar se ENCODER_PPR está correto (valor errado = velocidade medida errada).

### Garfo não segura a carga (desce sozinho)

- Se o motor não é worm gear: a redução não é auto-travante, precisa de freio
  mecânico ou PWM de manutenção.
- Se é worm gear mas ainda desce: a carga pode exceder o torque de retenção.
  Considerar um motor com maior relação de redução.

### GPIO 15 imprime lixo no boot

Normal — GPIO 15 HIGH no boot habilita debug output na UART. São ~100 bytes de
lixo na primeira vez. O `SetpointFrameDecoder` descarta automaticamente (quadros
sem '\n' válido são ignorados). Não causa problemas operacionais.
Desde 2026-07-06 o GPIO 15 é a fase B do encoder esquerdo: se o encoder o
segurar LOW no boot, as mensagens da ROM simplesmente somem — também inofensivo.

### ESP32 não entra em modo de gravação

O GPIO 2 (strapping pin) alimenta o encoder (`PIN_ENC_POWER_VCC`) e precisa
estar LOW/solto na gravação. A carga do encoder normalmente puxa o pino para
baixo, então costuma funcionar — se a gravação falhar, desconectar
temporariamente o fio do GPIO 2. O GPIO 5 (PWM do garfo, também strapping)
vai a uma entrada do L298n e em geral não interfere; se as chaves de
fim-de-curso um dia forem montadas, evitar GPIOs strapping para elas.

---

## 9. Decisões Pendentes (TODO)

Itens que podem precisar de ajuste após testes com o hardware real:

| Item | Onde | Status |
|---|---|---|
| Tensão dos encoders NXT (3.3V ou 5V?) | Fiação / level shifter | Verificar com multímetro |
| ENCODER_PPR = 1440 correto? | `config.h` | Validado 2026-07-06 (1 volta ≈ 1440; 10 voltas ≈ 14400) |
| Sentido dos motores (IN1/IN2) | `config.h` | Validado 2026-07-06 — canais A/B remapeados (ESQ=27/26/25, DIR=12/14/13) com `MOTOR_ESQ_INV=false`/`MOTOR_DIR_INV=true` |
| Ganhos PID (Kp=20, Ki=5, Kd=1) | `config.h` | Sintonizar com Ziegler-Nichols |
| FORK_DUTY = 220 adequado? | `config.h` | Ajustado na bancada 2026-07-06/07 (180→220 p/ levantar com carga); revalidar com o pallet real |
| Tipo dos switches (NO ou NC?) | `config.h` (`FORK_LIMIT_ACTIVE_LEVEL`) | Confirmar na montagem |
| BMS digital? | `main.cpp` / `config.h` | `has_bms = false` até definir |
| Faixa do giroscópio (±250°/s suficiente?) | `main.cpp` (configurar REG do MPU) | Provavelmente sim |
| Necessidade de debounce nos switches | `motors.cpp` | Avaliar se há ruído |

---

## Estrutura de Arquivos

```
firmware/
├── platformio.ini      # Config PlatformIO (espressif32@^6, ArduinoJson@^7)
├── README.md           # Este arquivo
├── src/
│   ├── main.cpp        # Loop principal (PID 100Hz + Serial 20Hz + watchdog)
│   ├── config.h        # todos os pinos, ganhos, taxas e constantes
│   ├── pid.h/cpp       # Controlador PID com anti-windup
│   ├── motors.h/cpp    # PWM/LEDC → L298n + garfo com fim-de-curso
│   ├── encoders.h/cpp  # Leitura de quadratura por ISR (IRAM_ATTR)
│   ├── protocol.h/cpp  # JSON+CRC8+\n framing + SetpointFrameDecoder
│   └── lib/            # (vazio — libs externas via lib_deps)
└── test/
    └── test_protocol/  # testes Unity do protocolo (`pio test -e esp32_test`)
```

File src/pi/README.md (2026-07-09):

# Empilhadeira — Backend Pi (Python)

## Arquitetura — 3 loops + WebSocket handler

`main.py` cria 3 `asyncio.create_task` no lifespan: Vision, Serial, Control.
O WebSocket handler roda por conexão (`@app.websocket("/ws")`).
Todas compartilham `SharedState` (`app/state.py`):

| Componente | Arquivo | Taxa | Função |
|---|---|---|---|
| Vision Loop | `tasks/vision_loop.py` | ~20 Hz | AprilTag → EKF correction |
| Serial Loop | `tasks/serial_loop.py` | 20 Hz | Setpoint ↔ sensores, EKF predict, GyroCalibrator, AttitudeKalman |
| Control Loop | `tasks/control_loop.py` | 20 Hz | Arbitragem (manual > missão > dock > legado) → setpoint, segurança |
| WebSocket Handler | `tasks/websocket_handler.py` | por conexão | Comandos, telemetria @20 Hz por cliente |

REST API (também em `main.py`): `/mission/*`, `/dock/*`, `/maps/*`, `/world-state`.
Pi serve `frontend/dist` como estático (modo operação sem Node).

## Estrutura

```
app/
├── main.py              # FastAPI + lifespan (troca SIM↔real)
├── config.py            # Parâmetros (provisórios marcados TODO(equipe))
├── state.py             # Estado compartilhado
├── models.py            # 4 contratos + telemetria estendida (Pydantic)
├── hardware/
│   └── interfaces.py    # VisionSource + SerialTransport (encaixes)
├── comms/
│   ├── protocol.py      # JSON + CRC8
│   └── serial_transport.py  # PySerialTransport (UART real)
├── control/             # ekf, navigation, path_planner, segment_executor, dock_to_tag,
│                        #   state_machine, kinematics, kalman, gyro_calibration, stanley_nav
├── mission/             # mission_sm (SM pick-and-place)
├── tasks/               # 3 loops asyncio + WS handler
├── vision/              # Detector, pose, calibração
├── world/               # Mapas JSON, robot model
└── sim/                 # Emulador (SIM=1 only)
```

## Como rodar

```bash
cd src && pip install -e ".[dev]"

# Simulação
SIM=1 ./scripts/run_pi.sh

# Hardware real (câmera + serial)
SIM=0 ./scripts/run_pi.sh

# Testes
python3 -m pytest pi/tests/ -v
```

## Modo SIM=1 vs SIM=0

| Componente | SIM=1 | SIM=0 |
|---|---|---|
| Visão | `SimVisionSource` | `RealVisionSource` (OpenCV) |
| Serial | `FirmwareEmulator` | `PySerialTransport` (UART) |
| Control loop, EKF, missão | idêntico | idêntico |

Troca em `app/main.py` → `lifespan()`. Detalhes:
[`docs/hardware-interfaces.md`](../docs/hardware-interfaces.md).

APIs extras em SIM=1: `/sim/reset-pose`, `/sim/inject-fault`, `/sim/world-state`,
`/sim/debug-dump`. Ver [`docs/simulation.md`](../docs/simulation.md).

## Deploy no hardware

Passo a passo completo: [`docs/hardware-deployment.md`](../docs/hardware-deployment.md).

Resumo mínimo:

1. Gravar firmware ESP32 (`firmware/`)
2. Calibrar câmera → `calibracao/camera_intrinsics.json`
3. Medir L, r, PPR → `config.py` + `config.h`
4. Criar mapa JSON da arena → `maps/`
5. `.env` com `SIM=0`, `SERIAL_PORT` (nota: `MAP=` no .env não tem efeito — mapa padrão hardcoded)
6. Smoke tests (joystick → AUTOMATICO → missão)

## Parâmetros provisórios (confirmar no robô)

| Parâmetro | Valor atual | Unidade |
|---|---|---|
| `WHEEL_BASE_L_CM` | 15.0 | cm |
| `WHEEL_RADIUS_R_CM` | 2.7 | cm |
| `ZREF_CM` | 15.0 | cm |
| `NAV_KZ` / `NAV_KX` / `NAV_KP_PITCH` | 0.5 / 0.80 / 0.1 | — |
| `NAV_MAX_APPROACH_SPEED` | 15.0 | cm/s |
| `APRILTAG_SIZE_CM` | 4.0 | cm |
| `CAMERA_TO_FORK_OFFSET_CM` | (0.0, -14.2, -10.0) | cm |
| `PALLET_MASS_KG` | 0.1 | kg |

Lista completa em `config.py` (grep `TODO(equipe)`).

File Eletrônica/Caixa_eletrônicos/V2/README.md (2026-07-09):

# Caixa de Eletrônicos — V2

<p align="center">
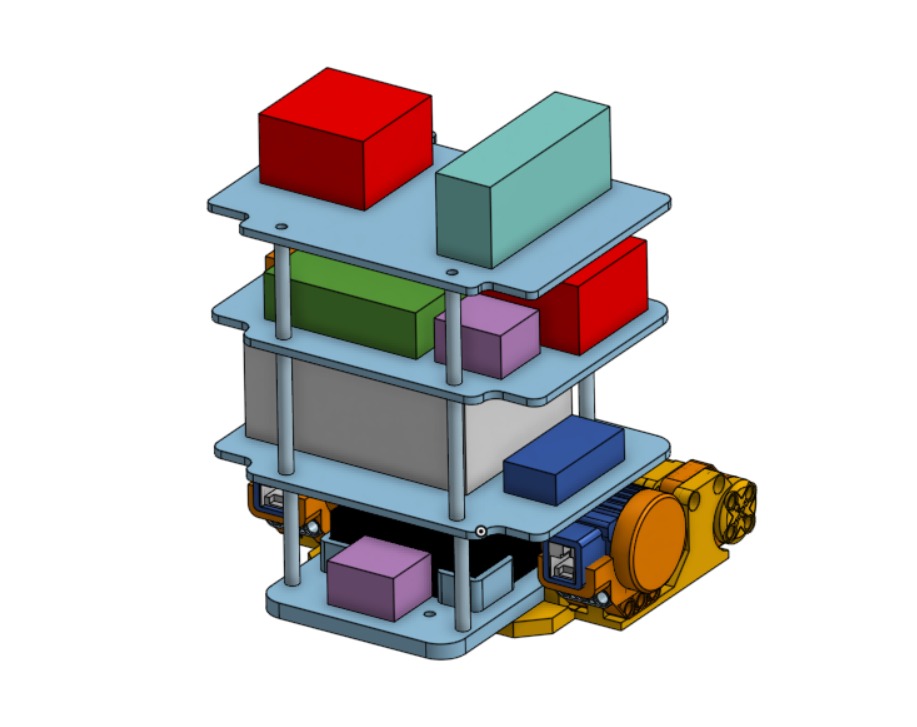
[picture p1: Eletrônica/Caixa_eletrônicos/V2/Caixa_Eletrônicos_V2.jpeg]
Caixa de Eletrônicos - V2
  
</p>

Segunda versão da caixa dos eletrônicos, dividida em andares empilháveis.
Modelos CAD na pasta: `Caixa-V2-Andar 1.step`/`.x_t` (andar 1) e
`Caixa-V2-andar 2,3,4.step`/`.x_t` (andares 2 a 4). Versão anterior:
[V1](../V1/README.md).

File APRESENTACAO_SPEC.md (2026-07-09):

# Apresentação — Empilhadeira Robótica Autônoma

Conteúdo organizado em três partes: (1) Visão, (2) Controle, (3) Comunicação.
A lógica está completa e validada em simulação e bancada; a autonomia no chão
ainda não rodou. Números extraídos do código e dos documentos do repositório.

---

## Visão geral do projeto

Empilhadeira robótica em escala reduzida que transporta pallets
(~15 cm de lado) em ambiente controlado, com dois modos de operação:

- MANUAL — operador dirige por joystick virtual no celular (navegador).
- AUTOMÁTICO — o robô navega sozinho entre AprilTags fixadas no mapa e
  executa uma missão pick-and-place: sorteia/recebe duas tags-alvo, navega
  até a de *pick*, para e espera o operador acionar o garfo, navega até a de
  *place*, espera o garfo de novo e volta para *home*.
- Regra de projeto: o garfo é sempre manual nos dois modos (canal de
  comando independente; nunca entra na malha autônoma).

Arquitetura hierárquica de 3 camadas (decisão fechada):

```
┌──────────────────────────────────────────────────────┐
│  FRONTEND — celular (React + Vite, navegador)         │
│  joystick · telemetria · missão · mapa · garfo        │
└──────────▲──────────────────────────┬─────────────────┘
     (2) telemetria @20Hz      (1) comando
         WebSocket / Wi-Fi            ▼
┌──────────┴─────────────────────────────────────────────┐
│  RASPBERRY PI — alto nível (Python, FastAPI + asyncio)  │
│  3 loops (Vision · Serial · Control) + WS handler        │
│                                                          │
│  AprilTag → EKF 2D → planejador → executor → setpoint   │
└──────────▲──────────────────────────┬───────────────────┘
     (4) sensores               (3) setpoint
     UART USB 115200, 20 Hz — JSON + CRC8 + \n
                                      ▼
┌──────────┴───────────────────────────────────────────────┐
│  ESP32 — baixo nível, tempo real (C++/Arduino, PlatformIO)│
│  PID por roda ~100 Hz · encoders · MPU-6050 · PWM → L298n │
└───────────────────────────────────────────────────────────┘
```

Simulação primeiro (sim-to-real):
toda a lógica do Pi (controle, missão, EKF, navegação, telemetria, protocolo)
roda idêntica em `SIM=1` e `SIM=0` — a simulação substitui exatamente duas
peças de hardware (câmera → visão sintética; ESP32 → emulador de firmware)
atrás das mesmas interfaces (`VisionSource`, `SerialTransport`). Resultado:

| Verificação (contagem de 2026-07-08) | Resultado |
|---|---|
| pytest (backend Pi) | 210 testes — 209 passam, 1 pulado |
| vitest (frontend) | 11/11 passam |
| `sim_sweep.py` (9 cenários de aproximação) | 9/9 convergem (parada a 15,0–16,3 cm; offset lateral ≤ 2,4 cm; erro de heading ≤ 3,7°) |
| `full_trace.py` (13 cenários) | 12/13 (o 13º é LOST esperado — tag fora do FOV) |

Linha do tempo (commits): 12/05 início (aula, scripts de AprilTag) →
26/05 scaffold do monorepo → 02/06 visão v1 → 09/06 firmware ESP32 + protocolo
serial → 15–16/06 simulação completa + frontend v1 → 23/06 integração
(EKF, planejador, missão, mapas, docs) → 03/07 calibração da câmera antiga +
correções → 06/07 dia de bancada no robô real (encoders, motores, sinais,
v_máx medida, dock-to-tag, D-pad) → 07/07 câmera nova remontada (tilt de 30°)
e recalibrada a 1280×720.

Estado em 2026-07-06: eletrônica validada na
bancada (encoders, motores, PID convergindo, watchdogs, telemetria/CRC/MPU) e
v_máx medida no chão; Fase 2 (manual no chão) e Fase 3 (autonomia) do plano
de testes ainda não rodaram no hardware — a autonomia completa foi validada
apenas em simulação e testes de unidade.

Hardware: Raspberry Pi + câmera USB · ESP32 · 2× ponte-H L298n · 2 motores
Lego NXT 53787 (rodas) + motor JGY-370 12 V com rosca sem-fim (garfo) ·
encoders de quadratura 1440 pulsos/volta (decodificação x4) · IMU MPU-6050
(I2C) · arena real: corredor 0,80 × 1,60 m com 6 AprilTags
(mapa `corredor_6tags_80x160.json`).

---

## Parte 1 — Visão

### 1.1 O que a visão faz

É o único sensor absoluto do robô. Ela responde duas perguntas:
1. **Reativa:** "onde está a tag à minha frente?" → `z_cm` (distância),
   `x_cm` (deslocamento lateral), `pitch_deg` (ângulo da face da tag) — usados
   pela aproximação reativa e pelo dock-to-tag.
2. **Global:** "onde o robô está no mapa?" → cada tag detectada tem pose conhecida
   no mapa JSON; por PnP inverte-se a observação e obtém-se a pose absoluta do
   robô, que corrige o EKF (a odometria sozinha deriva).

### 1.2 Pipeline

```
Câmera USB (1280×720) → grayscale → pupil-apriltags (tag25h9, PnP com
intrínsecos) → detecções {id, pose_R, pose_t} →
  ├─ VisionState (tag mais próxima): detectado, id, z_cm, x_cm, pitch_deg
  └─ TagObservations (todas as tags) → correção do EKF [x, y, θ]
```

- **Biblioteca:** `pupil-apriltags` (bindings do detector oficial da AprilRobotics)
  + OpenCV. Família `tag25h9`.
- **Detector:** `quad_decimate=2.0` (detecção em meia resolução, cantos
  refinados em resolução cheia — perda de precisão de pose desprezível,
  custo ~4x menor), `refine_edges=1`, `decode_sharpening=0.25`,
  `estimate_tag_pose=True` com `camera_params=(fx,fy,cx,cy)` e
  `tag_size=0,04 m`.
- Tamanho físico da tag: **4 cm** (0,04 m) — medido e reconciliado nos três
  lugares que precisam concordar (config do Pi, mapas JSON, default do
  detector). Se a tag impressa não tiver exatamente 4 cm, o `z` sai
  proporcionalmente errado (checagem com paquímetro está no plano de teste).
- **Vision Loop:** tarefa asyncio a 20 Hz; a leitura bloqueante da câmera
  (OpenCV) roda em `asyncio.to_thread` para não travar o event loop do
  backend. Um frame por tick alimenta tanto o estado reativo quanto o EKF
  (sem captura dupla).

### 1.3 Calibração da câmera (recalibração 2026-07-07)

- Câmera nova, remontada com tilt de 30°; recalibrada em 2026-07-07 com
  tabuleiro de xadrez OpenCV (`findChessboardCorners` + `calibrateCamera`)
  a **1280×720**.
- Intrínsecos atuais (`pi/calibracao/camera_intrinsics.json`):
  `fx=fy=1023,63 · cx=634,08 · cy=377,08`, com coeficientes de distorção
  completos `[k1,k2,p1,p2,k3] = [0,0403, -0,0243, 0,0029, -0,0019, -0,0493]`;
  cx/cy a 6/17 px do centro geométrico da imagem. Erro de reprojeção não
  registrado no JSON.
- Histórico: a calibração de 03/07 (câmera antiga, 640×480, 28 fotos, cantos
  internos 8×5, quadrado de 3 cm, erro de reprojeção 0,144 px, cx=399 —
  anômalo) foi descartada junto com a câmera.
- Regra: a resolução de captura tem que ser a mesma da calibração
  (1280×720, `CAMERA_FRAME_WIDTH/HEIGHT` no config); com
  `REQUIRE_CAMERA_CALIBRATION=1` o backend se recusa a subir em modo real
  sem calibração válida.
- Validação planejada com fita métrica: tag a 30,0 cm → `z` entre 28,5–31,5 cm;
  ainda detectar a 15 cm (standoff de navegação); anotar alcance máximo.

### 1.4 Mundo paramétrico (mapas)

A arena não é hardcoded: mapas JSON em `pi/maps/` declaram dimensões, tags
(`position_id`, `x_m`, `y_m`, parede, `yaw_deg`), pose inicial, pose *home* e
grafo opcional de waypoints. Trocar de arena = trocar um arquivo. O mapa real
medido é `corredor_6tags_80x160.json` (0,80×1,60 m, tags L1–L3 e R1–R3).
Schema validado por Pydantic (IDs únicos, tags dentro da arena, arestas do
grafo válidas).

### 1.5 Fusão visão + IMU + odometria (EKF 2D)

- Estado `[x, y, θ]`. **Predição** @20 Hz: odometria dos encoders + giroscópio
  Z (mistura de heading: 70% gyro / 30% odometria).
- **Correção** quando vê tag: pose absoluta por PnP contra o mapa; ruído de
  observação escalado pela qualidade da detecção (`decision_margin`);
  **gating de Mahalanobis a 3σ** rejeita detecções inconsistentes com a
  estimativa corrente (um falso positivo não desloca a pose estimada).
- Telemetria exporta elipse de covariância 95% para desenhar a incerteza na UI.

### 1.6 Visão sintética (simulação)

Em `SIM=1` a câmera é substituída por um modelo analítico: FOV 60°, alcance
3–150 cm, ruído gaussiano de ±0,2 cm / ±0,5°, com injeção de falhas
(`tag_hidden`, `vision_blur`, `vision_drop`). Os 9/9 cenários de aproximação
foram validados nesse modo, antes do hardware existir.

### 1.7 Dock-to-tag (06/07)

Modo ligado por default (`DOCK_TO_TAG_ENABLED = True` desde 2026-07-07): o
robô vê uma tag, planeja uma única vez uma rota de segmentos discretos
(FORWARD/TURN) até um standoff de 15 cm de frente para a tag e executa por
odometria/EKF — a mesma maquinaria da missão (SegmentExecutor), sem
pick/place. Por isso serve de ensaio para a navegação da missão. Segmentos
discretos toleram perder a tag do FOV numa curva de 90° (não é servo contínuo). Dois
modos: `line_of_sight` (default; usa só z/x, não depende de convenção de yaw)
e `tag_normal` (esquadra com a face da tag; convenção de yaw com offset π
validada na bancada em 2026-07-07). Estados: SEEKING → DOCKING → DONE/FAULT; teste
fechado exige estacionar a < 5 cm do standoff. Junto veio o endpoint
`GET /world-state`, que faz a "vista de cima" da UI funcionar no robô real.

### 1.8 Problemas de visão encontrados e correções

1. **Sinal do X invertido** — o frame óptico do OpenCV tem x positivo = tag à
   direita; a convenção do projeto (herdada do simulador e da navegação) é
   x positivo = tag à esquerda. Sem a negação na fronteira (`pose.py`), a
   autonomia real viraria para o lado oposto da tag — em simulação o problema
   não aparecia porque a visão sintética já nascia na convenção do projeto.
   Corrigido em 06/07. Lição: converter convenções na fronteira entre os dois
   mundos e validar sinais no hardware um a um.
2. **Tamanho da tag inconsistente (5 cm vs 4 cm)** — o legado usava 0,05 m;
   a tag impressa real tem 4 cm. Como `z` escala linearmente com o tamanho
   declarado, isso era um erro sistemático de 25% em toda distância.
   Reconciliado para 0,04 m nos três lugares de uma vez (config, mapas,
   detector).
3. **`dist_coeffs` em formato dict** — a calibração salva os coeficientes como
   dicionário nomeado; o loader passou a aceitar dict OU lista e reordenar
   para o formato OpenCV `[k1,k2,p1,p2,k3]`.
4. **OpenCV quebrado no Pi** — instalações duplicadas/parciais do OpenCV
   deixavam `cv2` sem `VideoCapture`; o harness `teste_cam.py` agora falha
   cedo com diagnóstico claro e receita de correção, e detecta automaticamente
   o modo headless quando rodando via SSH (sem display).
5. **Resolução ≠ calibração (resolvido)** — a 2ª calibração (2026-07-07) é em
   1280×720, que agora coincide com o default do config. Intrínsecos só valem
   na resolução em que foram medidos — o vision_loop força o `image_size` do
   JSON de calibração na captura.
6. **Ambiguidade de pose / convenção de yaw (parcialmente fechado)** — estimar
   a orientação de uma tag pequena tem ambiguidade conhecida. A convenção do
   `pitch_deg` (negado na fronteira, offset π) foi validada na bancada em
   2026-07-07, o que liberou a estratégia `tag_normal` do dock; a correção de
   **heading** do EKF por yaw de tag segue com `TODO(equipe)` para validação
   no hardware (`pose.py`). O default do dock continua `line_of_sight`.

---

## Parte 2 — Controle

### 2.1 A ideia central: malha em cascata (2 níveis, 2 processadores)

```
Pose alvo (mapa)
   ↓
PathPlanner  → lista de segmentos [FORWARD 1.2m, TURN 90°, ...]
   ↓
SegmentExecutor — malha externa no Pi @20 Hz
   pose do EKF → (v, ω) → (ω_esq, ω_dir) em rad/s
   ↓  setpoint via serial
PID por roda no ESP32 — malha interna @100 Hz
   ω medido (encoder) → duty PWM → L298n → motor
```

Regra: o Pi nunca duplica o PID de roda — a malha externa cuida de
posição/heading, a interna de velocidade. Divisão também de *tempo real*: o
ESP32 garante determinismo a 100 Hz; o Pi roda a 20 Hz com Python/asyncio.

### 2.2 Baixo nível (ESP32 — C++/Arduino/PlatformIO)

- **PID por roda @100 Hz:** ganhos iniciais **Kp=20, Ki=5, Kd=1** (motores
  Lego NXT a 12 V via L298n), anti-windup com integral limitada a ±500.
  Sintonia final planejada por Ziegler-Nichols no chão (os ganhos foram
  acertados com a roda no ar; com carga a dinâmica muda — overshoot ~10%
  já observado a 8 rad/s).
- **PWM:** LEDC do ESP32 a 20 kHz (acima da faixa audível), 8 bits (0–255).
- **Encoders de quadratura, decodificação x4:** interrupções em CHANGE nas
  duas fases, tabela de transição de 16 entradas (ISR em IRAM; transição
  inválida = 0, o que cancela bounce naturalmente) → **1440 contagens/volta**.
- **IMU MPU-6050 cru pela serial:** acelerômetro ±2g e gyro ±250°/s enviados
  crus (m/s², °/s) — toda a fusão é feita no Pi (decisão: manter o firmware
  simples e determinístico; a filtragem fica onde há ponto flutuante e testes
  fáceis).
- **Watchdog local:** sem setpoint válido por **200 ms** (4 mensagens perdidas
  @20 Hz) → motores zerados + PID resetado. É a última linha de defesa, não
  depende de nada acima.
- **Garfo:** duty fixo, rosca sem-fim segura a carga parada (sem esforço em
  PARAR); fins-de-curso previstos no código mas desabilitados (não montados).

### 2.3 Alto nível (Pi — Python)

- **EKF 2D `[x, y, θ]`** (detalhes na Parte 1): predição por
  odometria + gyro, correção por AprilTag, gating 3σ.
- GyroCalibrator — calibração automática no boot: com o
  robô parado ~2–3 s, usa a gravidade para descobrir qual eixo do
  MPU aponta para cima, o sinal do yaw (projeção do gyro no vetor "up" de
  um sensor destro) e o bias de taxa-zero (com rastreamento térmico lento
  por EMA). Consequência prática: a posição/orientação física do MPU no chassi
  não importa — o sensor pode ser remontado sem mudança de código.
  Procedimento de boot: robô imóvel em chão firme por 3 s (pneus macios
  balançam o chassi; calibrar com o chassi oscilando faz o heading derivar).
- **PathPlanner:** A* sobre o grafo de waypoints do mapa quando existe;
  fallback Manhattan (alinha X, depois Y) quando não. Saída: segmentos
  FORWARD/TURN com pose-alvo.
- **SegmentExecutor (malha externa):** FORWARD com `v = K_DIST·dist` e correção
  de heading `ω = K_HEADING·erro` (se o erro de heading passa de 45°, para e
  gira primeiro); TURN girando no lugar até tolerância de ~4° (`NAV_HEADING_TOL_RAD=0.07`);
  tolerância de posição 2 cm; timeout de segmento 45 s → FAULT da missão.
- **Navegação reativa legada (1 tag): APPROACH → FACE → RETREAT**, controle
  por *bearing* proporcional, desaceleração limitada
  (`v = √(2·a·d)`), zona morta com histerese, detector de oscilação (conta
  trocas de sinal de ω numa janela) com fallback. Uma análise comparativa
  (Stanley, Pure Pursuit, bearing unificado — `compare_nav.py`) concluiu que o
  mode-switching reativo é o adequado para robô diferencial com câmera frontal;
  o Stanley ficou no repo como alternativa experimental.
- **Máquina de missão pick-and-place:**
  `IDLE → LOAD_MAP → DRAW_TARGETS → GO_TO_PICK → AT_PICK → GO_TO_PLACE →
  AT_PLACE → GO_HOME → DONE`, com ramo FAULT de qualquer estado. Em AT_* o
  robô para e espera o operador acionar o garfo e clicar
  "continuar". Sorteio de alvos com seed reprodutível.
- **Modos de operação:** MANUAL / AUTOMÁTICO / PARADO com **latch de
  segurança** — parada por segurança trava e só um comando explícito do
  operador destrava (sem o latch, o loop de 20 Hz re-entraria no modo ativo a
  cada tick, oscilando).

### 2.4 Números de calibração medidos

| Grandeza | Valor | Como |
|---|---|---|
| v_máx real no chão | **24,0 cm/s** | cronometrado: 100 cm em 4,16 s em comando máximo (06/07) |
| `MAX_LINEAR_SPEED` | **19 cm/s** (~80% da medida) | folga p/ PID + queda de bateria |
| `MAX_ANGULAR_SPEED` | 2,5 rad/s (provisório) | derivado do teto físico; falta cronometrar 1 volta |
| Raio da roda | 2,7 cm | medição da equipe; confirmar por teste de rolagem (o pneu deforma sob carga) |
| Entre-eixos (wheelbase) | 15 cm | refinar pelo giro de 360° |
| Encoder | 1440 pulsos/volta (x4) | validado na bancada, ±sinais conferidos |
| Standoff de aproximação | 15 cm (ZREF) | 5 cm causava overshoot na sim |
| PID roda | Kp=20 · Ki=5 · Kd=1, integral ±500 | inicial; Ziegler-Nichols no chão se precisar |

### 2.5 Problemas de controle encontrados e correções

1. **Canais dos motores trocados na fiação (bancada, 06/07):**
   o canal A do L298n acionava a roda direita e o B a esquerda — o inverso do
   rótulo do código de referência da eletrônica. Com isso as malhas PID
   ficaram cruzadas: cada PID lia o encoder de uma roda e acionava a outra.
   Sintoma: uma roda saturava no máximo e a outra morria, alternando o
   lado aleatoriamente entre testes (realimentação positiva: o PID acelera, a
   "sua" roda não responde, integral explode). Corrigido por remapeamento em
   software no `config.h`. Lição: testar sempre um lado por
   vez (`--w-esq X --w-dir 0`) — o teste com as duas rodas juntas não detecta
   canais trocados.
2. **Encoder esquerdo sobrecontando ~420 pulsos/volta:** estava nos GPIOs
   34/35, que são input-only e não têm pull-up interno — linha flutuando
   = contagem por ruído. Refiado no mesmo dia para 23/15 (com `INPUT_PULLUP`).
   Na mesma intervenção, a decodificação passou de x1 para x4 completa com
   tabela de transição, que rejeita bounce por construção.
3. **Parada incondicional em setpoint zero:**
   com um encoder morto (medida=0), o comando de parar tinha erro 0 mas a
   integral acumulada segurava o duty no máximo — o robô ignorava o comando
   de parada. Correção de segurança no firmware: setpoint 0 = parada
   incondicional que bypassa o PID e reseta a integral. O robô fica seguro e
   dirigível mesmo com encoder com defeito.
4. **MPU-6050 em sleep / barramento I2C caindo:** duas assinaturas distintas
   diagnosticadas no stream: (a) tudo-zero com `temp = 36,53 °C` = sensor
   em sleep (o I2C responde 14 bytes zerados; 36,53 °C é o offset da fórmula
   de temperatura com leitura crua = 0, o que identifica a condição);
   (b) tudo-zero com `temp = 0` + erro do driver Wire = queda do barramento
   (contato/EMI perto do L298n).
   Correções: o firmware se recupera re-enviando o wake após ~1 s de
   leituras mortas; e o GyroCalibrator no Pi descarta frames mortos
   (‖accel‖ < 2 m/s² é fisicamente impossível com o sensor operando)
   para não corromper a média de gravidade nem erodir o bias.
5. **Oscilação com heading > 45° → fase COARSE_ALIGN:** quase perpendicular à
   tag, recalcular ω a cada frame criava um ciclo-limite (pequenas rotações
   trocavam o sinal da leitura). Correção: girar com ω fixo e direção travada
   na entrada, com histerese (entra a 45°, sai a 35°), e só então APPROACH.
6. **Gravação do firmware falhando (`chip stopped responding`):** os encoders
   estavam alimentados pelos GPIOs 2/4 — e o GPIO 2 é pino de strapping de
   boot do ESP32. Sequência de troubleshooting documentada (segurar BOOT,
   desconectar o fio do GPIO 2, desligar a fonte 12 V durante a gravação).
7. **Ganhos de bancada ≠ chão (assumido no prontuário):** atrito estático faz
   o robô não partir com comando baixo (comportamento esperado — a integral
   acumula devagar); bateria caindo faz o PID saturar antes.

### 2.6 Bugs encontrados em simulação antes do hardware

Bugs corrigidos ainda em sim: AUTOMÁTICO congelava após 1 comando (control
loop desacoplado do frontend), PARADO oscilava sem latch, deadlock de rotação
no fallback, integral do PID não resetava em PARADO, ZREF=5 cm com overshoot
(→15 cm), perda de tag com offset lateral (bearing guard + histerese), omega
bang-bang (→ proporcional por bearing), FACE de 1–2 ticks (→ mínimo 0,5 s),
parada falsa a 24–25 cm (dead zone com histerese). Nenhum deles precisou do
robô físico para ser encontrado.

---

## Parte 3 — Comunicação

### 3.1 Os 4 contratos congelados

O sistema tem exatamente 4 contratos de dados, documentados em
`serial-protocol.md` e espelhados em três linguagens: Pydantic (Python/Pi),
structs C++ (firmware) e TypeScript (frontend). Mudou o contrato, muda nos
três.

```
(1) comando    Frontend → Pi     WebSocket/Wi-Fi   JSON       {modo, joystick{x,y}, garfo, ts_ms}
(2) telemetria Pi → Frontend     WebSocket @20 Hz  JSON       estado, rodas, imu, visão, EKF, missão, nav, dock, tags, mapa, parado_reason
(3) setpoint   Pi → ESP32        UART @20 Hz       JSON+CRC8  {"w_esq":rad/s, "w_dir":rad/s, "garfo":"subir|descer|parar"}
(4) sensores   ESP32 → Pi        UART @20 Hz       JSON+CRC8  {enc{esq,dir}, mpu{ax..gz,temp_c}, bms:null}
```

### 3.2 Serial Pi ↔ ESP32 (UART USB, 115200 baud, 20 Hz)

- **Framing:** `<json compacto>*<crc8 em 2 hex minúsculos>\n`.
  Exemplo real: `{"w_esq":1.5,"w_dir":1.5,"garfo":"parar"}*a3\n`.
- **Checksum CRC-8/MAXIM (Dallas/1-Wire)** — polinômio 0x31 refletido,
  implementado idêntico em Python e C++, com testes de unidade dos dois lados
  comparando vetores conhecidos.
- Descarte de frames inválidos: os decodificadores dos dois lados são
  incrementais (byte a byte), ressincronizam no `\n` e descartam o frame
  inteiro em CRC/JSON/schema inválido — frame ruim nunca vira comando; no pior
  caso vira watchdog.
- No Pi, o transporte é `pyserial-asyncio` dentro do Serial Loop @20 Hz: envia
  o setpoint corrente, lê frames de sensores, alimenta o Kalman de atitude e a
  predição do EKF a cada tick.

### 3.3 WebSocket + REST (Pi ↔ celular)

- **FastAPI** com WebSocket `/ws`: comandos entram validados por Pydantic
  (inválido = descartado com warning, nunca derruba o handler); telemetria sai
  a 20 Hz. Desconectou → `force_stop` imediato + comando limpo.
- **REST:** mapas (`GET /maps/list`, `POST /maps/load/{name}`,
  `GET /maps/{name}`, `GET /maps/current`), missão (`/mission/start`,
  `/continue`, `/reset`, `/state`), dock (`/dock/enable`, `/disable`,
  `/state`), `GET /world-state` (vista de cima real). Em SIM, endpoints extras
  de injeção de falha (`/sim/inject-fault`: serial_drop, tag_hidden,
  wheel_slip, vision_blur/drop, encoder_noise, gyro_drift), reset de pose e
  `debug-dump` completo (exportável em TXT/CSV pela UI).
- Frontend React + Vite + Tailwind, páginas: operador (joystick, D-pad,
  garfo, modo, telemetria, alertas), mapa e demo (arena vista de cima, missão,
  injeção de falhas, export de debug).

### 3.4 Cadeia de segurança fim-a-fim

Cada enlace tem seu próprio watchdog — a falha de qualquer elo para o robô:

| Elo que cai | Vigia | Limite | Ação |
|---|---|---|---|
| Celular↔Pi (Wi-Fi, em MANUAL andando) | Command watchdog (Pi) | **400 ms** | PARADO com latch, motivo `command_watchdog` |
| WebSocket fecha | Handler (Pi) | imediato | `force_stop` + comando limpo |
| Tag some em AUTOMÁTICO | Tag-loss (Pi) | 5 frames (~250 ms) | PARADO com latch (suspenso durante missão/dock — a tag sai do FOV em curvas normais; aí valem PARADO na UI e os watchdogs abaixo) |
| UART para de entregar sensores | Serial lost-frames (Pi) | 5 ciclos (~250 ms) | `force_stop`, motivo `serial_loss` |
| Setpoint para de chegar no ESP32 | Setpoint timeout (firmware) | **200 ms** | motores zerados + PID resetado, local, independe de tudo |

- O **latch** existe porque o control loop repropõe o modo do operador a
  20 Hz — sem trava, o robô re-entraria no modo ativo a cada tick.
- Os valores foram fechados como contrato: 400 ms > RTT alvo (<170 ms) +
  heartbeat do frontend (100 ms); o 200 ms do firmware = 4 mensagens perdidas.
- Validado na bancada: Ctrl-C com rodas girando → parada em menos de 200 ms.

### 3.5 D-pad "Comando exato" (06/07)

Painel com botões que enviam vetores puros: Frente = ω exatamente 0
(reta), Gira = v exatamente 0 (giro no lugar), em 30/60/100% da
velocidade máxima — remove a variação manual do joystick dos testes de
retidão e odometria (1 m medido com fita; 360° e conferir o heading).
Cada botão re-envia o vetor a cada 100 ms (heartbeat) para satisfazer o
command watchdog de 400 ms; ao soltar, envia `{0,0}` imediatamente.

### 3.6 Duas topologias de rede (decisão operacional)

- **Modo dev** (desenvolvimento): frontend servido pelo Mac (`npm run dev`,
  porta 5173, exposto na rede), backend no Pi; o celular abre a página do Mac
  e o WebSocket aponta para o Pi via `VITE_PI_WS_URL=ws://<IP_DO_PI>:8000/ws`
  (obrigatório neste modo — o fallback de mesmo-host apontaria para o Mac).
- **Modo operação** (demo/desafio): `npm run build` no Mac, `rsync` do `dist/`
  para o Pi, e o backend FastAPI serve o frontend estático na própria porta
  8000 (montado por último, com fallback SPA para o BrowserRouter) —
  sem Node/npm no Pi, uma porta só, e o WebSocket resolve sozinho para o
  host da página. O celular abre `http://<IP_DO_PI>:8000/`.

### 3.7 Problemas de comunicação encontrados e correções

1. **WebSocket "flapping" (React 18 StrictMode):** em dev, o StrictMode monta
   componentes duas vezes; o socket órfão da primeira montagem disparava
   `onclose` e agendava reconexões em cima do socket vivo — tempestade de
   conexões, UI alternando "Conectado/Desconectado". Correção: todo handler
   valida `wsRef.current !== ws` (socket órfão é ignorado), `connect()` não
   abre se já há socket OPEN/CONNECTING, cleanup anula os handlers antes de
   fechar, e reconexão tem backoff exponencial 500 ms → 10 s.
2. **Watchdog de comando 500 → 400 ms:** valor renegociado ao unificar os
   branches (contrato de segurança adotado do main), documentado em todos os
   docs afetados.
3. **Watchdog serial existia mas não estava ligado:** o `SERIAL_LOST_FRAMES`
   foi efetivamente conectado ao `serial_loop_real` num fix dedicado — lição:
   segurança não é o parâmetro existir, é o caminho de código rodar.
4. **`VITE_PI_WS_URL` ignorado:** o frontend não honrava a env e conectava no
   host errado no modo DEV; corrigido como parte do "contrato" de env
   (`envDir` apontando para o `.env` do monorepo).
5. **uvicorn/uv:** migração da toolchain para `uv` + `uvicorn[standard]`
   (inclui websockets/uvloop) com lockfile — deploy reprodutível no Pi;
   `requirements.txt` completo e fixado para o deploy real.
6. **Porta serial é uma só:** monitor do PlatformIO, script de bancada e
   backend disputam a UART (`Device or resource busy`) — virou regra
   operacional no plano de testes: fechar um antes de abrir o outro.
7. **BMS previsto no contrato mas não integrado:** o campo `bms` viaja como
   `null` — o contrato já reserva o lugar sem quebrar ninguém quando chegar.

---

## 4. Status (2026-07-07)

Feito e validado
- Lógica validada em simulação: 210 testes backend (pytest) + 11 frontend (vitest),
  9/9 cenários de aproximação convergem, missão completa em 4 mapas.
- Bancada (06/07): encoders x4 validados (sinais, PPR 1440, isolamento),
  canais/sentido dos motores corrigidos e conferidos um a um, PID convergindo,
  watchdog serial < 200 ms medido, telemetria/CRC/MPU sãos, todas as
  convenções de sinal do firmware confirmadas no stream cru.
- Câmera nova recalibrada (07/07, 1280×720, fx=fy=1023,63) após remontagem
  com tilt de 30°.
- v_máx medida no chão (24 cm/s) e configurada com folga (19 cm/s).
- Dock-to-tag + vista de cima real implementados e passando em teste de unidade.
- Modo operação (Pi sozinho servindo tudo, sem Node) funcionando.

Falta (em ordem, do plano de testes)
- Fase 2 no chão: manual completo (retidão, ré, sinais de giro no chão),
  garfo com carga, watchdogs com o robô em movimento, sanidade de odometria
  (1 m e 360°).
- Medições restantes: raio por rolagem, bitola refinada, ω máx cronometrado,
  offset câmera→garfo, tag no paquímetro.
- Últimas convenções de sinal no hardware: `x_cm` e `pitch_deg` foram
  validadas na bancada em 2026-07-07; restam o sinal do `gz` no giro à mão e
  a correção de heading do EKF por yaw de tag.
- Fase 3 inteira (autonomia) ainda não rodou no hardware: aproximação reativa
  → segurança em autonomia → EKF no corredor → dock → missão 3× seguidas →
  ensaio geral do dia D.

Riscos conhecidos e mapeados (prontuário): ganhos de bancada vs chão,
raio efetivo desigual entre pneus, queda de tensão da bateria (PID satura
antes), Wi-Fi do local com RTT > 400 ms, escorregamento nas curvas de 90°
degradando odometria, tag impressa fora de medida. Cada um com sintoma e
ação documentados.

---

## 5. Lições de engenharia

1. Simulação com as mesmas interfaces compensa o investimento: dezenas de
   bugs de lógica foram corrigidos antes do robô existir; no hardware sobraram
   só os bugs de hardware (fiação, sinais, ruído) — os que a simulação não cobre.
2. Convenções de sinal são a fronteira mais arriscada do sim-to-real:
   OpenCV vs projeto, joystick vs ω, encoder vs sentido — todos os bugs de
   06/07 foram de sinal, nenhum de lógica. Validar um a um, com checklist.
3. Segurança em camadas independentes: 5 watchdogs em 3 processadores;
   qualquer elo caindo para o robô, e o de baixo (200 ms no firmware) não
   depende de nada acima.
4. Teste um grau de liberdade por vez: o teste com as duas rodas juntas
   não detecta canais trocados; o D-pad de comandos puros existe pelo mesmo
   motivo.
5. Contratos congelados e espelhados em 3 linguagens evitam a deriva
   frontend/Pi/firmware; frame inválido se descarta, não se interpreta.
6. Parâmetro medido em vez de estimado: v_máx cronometrada com fita e
   gravada a 80%; nenhum valor inventado (política "não inventar valores",
   com `TODO(equipe)` em cada placeholder).
7. Diagnóstico escrito vira ativo: as duas assinaturas de falha do MPU e o
   prontuário de sintomas aceleram o diagnóstico do próximo bug.

---

## Apêndice — Tabela de números para consulta rápida

| Item | Valor |
|---|---|
| Arena real | corredor 0,80 × 1,60 m, 6 tags |
| AprilTag | família tag25h9, **4 cm** |
| Câmera | USB, **1280×720**, fx=fy=1023,63 · cx=634,08 · cy=377,08 (recalibração 2026-07-07, xadrez OpenCV, pós-remontagem com tilt de 30°) |
| Loops no Pi | 3 no startup: Vision · Serial · Control (20 Hz cada); Telemetria via WebSocket handler por conexão |
| PID firmware | 100 Hz, Kp=20 Ki=5 Kd=1, anti-windup ±500, PWM 20 kHz 8 bits |
| Encoders | quadratura x4, 1440 pulsos/volta |
| EKF | estado [x,y,θ]; heading 70% gyro + 30% odom; gate Mahalanobis 3σ |
| Serial | UART USB 115200 baud, 20 Hz, JSON + CRC-8/MAXIM + `\n` |
| Watchdogs | comando 400 ms · serial 5 frames (~250 ms) · firmware 200 ms · tag-loss 5 frames · WS disconnect imediato |
| Velocidades | v_máx medida 24 cm/s → config 19 cm/s · ω 2,5 rad/s (provisório) |
| Geometria | roda r=2,7 cm · entre-eixos 15 cm · standoff 15 cm |
| Missão | IDLE→LOAD_MAP→DRAW_TARGETS→GO_TO_PICK→AT_PICK→GO_TO_PLACE→AT_PLACE→GO_HOME→DONE (+FAULT) |
| Verificação | 210 pytest + 11 vitest + 9/9 sim_sweep + 12/13 full_trace |
| Stack | Pi: Python/FastAPI/asyncio/OpenCV/pupil-apriltags/filterpy · ESP32: C++/Arduino/PlatformIO/ArduinoJson · Front: React/Vite/Tailwind |

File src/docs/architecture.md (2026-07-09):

# Arquitetura — Empilhadeira Robótica Autônoma

Empilhadeira robótica em escala reduzida que transporta pallets (~15 cm de lado) em
ambiente controlado. Dois modos de operação:

- **Manual:** operador comanda o robô por joystick virtual no celular.
- **Autônomo:** o robô executa missões de navegação entre AprilTags no mapa,
  posicionando-se em frente aos alvos (apenas posicionamento, não manipulação).

O garfo é sempre manual nos dois modos, num canal de comando independente.

## Missão pick-and-place com garra manual

Além do posicionamento reativo legado (aproximar de uma tag visível), o sistema
suporta uma **missão pick-and-place** completa:

1. Sorteia ou recebe dois alvos (`position_id`) do mapa carregado
2. Navega autonomamente até a tag de **pick**
3. Para e aguarda o operador acionar a garra manualmente
4. Navega até a tag de **place**
5. Aguarda novo acionamento manual da garra
6. Retorna ao ponto **home** do mapa

Detalhes da máquina de estados e da API REST em [`mission.md`](./mission.md).

## Arquitetura hierárquica de 3 camadas

```
┌─────────────────────────────────────────────────────────────────┐
│  FRONTEND — Celular (React + Vite, navegador)                   │
│  Joystick · telemetria · missão · seletor de mapa · garfo       │
└───────────────▲───────────────────────────┬─────────────────────┘
                │ (2) telemetria @20Hz       │ (1) comando
                │     WebSocket / Wi-Fi      ▼
┌───────────────┴─────────────────────────────────────────────────┐
│  RASPBERRY PI — Alto nível (Python, FastAPI + asyncio)           │
│  3 loops asyncio no startup + handler WebSocket por conexão:       │
│   • Vision Loop · Serial Loop · Control Loop                      │
│   • WebSocket Handler (FastAPI, telemetria @20 Hz por cliente)     │
│  Visão (AprilTag), EKF 2D, Kalman 1D (roll/pitch),               │
│  GyroCalibrator, cinemática, planejador de rotas,                │
│  executor de segmentos, dock-to-tag, missão pick-and-place,      │
│  máquina de estados/segurança, modelo de mundo, protocolo.       │
└───────────────▲───────────────────────────┬──────────────────────┘
                │ (4) sensores               │ (3) setpoint
                │     UART USB 115200, 20 Hz │     JSON+CRC8+\n
                │                            ▼
┌───────────────┴─────────────────────────────────────────────────┐
│  ESP32 — Baixo nível, tempo real (C++ / Arduino, PlatformIO)     │
│  PID por roda ~100 Hz · leitura encoder/MPU · PWM (LEDC)→L298n   │
│  Garfo manual + fim-de-curso local                               │
└──────────────────────────────────────────────────────────────────┘
```

Os contratos de dados entre camadas estão congelados em
[`serial-protocol.md`](./serial-protocol.md) — fonte única de verdade.

## Loops asyncio no Pi

`main.py` cria 3 `asyncio.create_task` no lifespan: Vision Loop, Serial Loop,
Control Loop. O WebSocket Handler roda por conexão via `@app.websocket("/ws")` —
não é um quarto loop no startup.

| Componente | Taxa | Responsabilidade |
|---|---|---|
| **Vision Loop** | ~20 Hz | Detecção AprilTag (real ou sintética), correção EKF, cache multi-tag |
| **Serial Loop** | 20 Hz | Troca setpoint/sensores com ESP32 ou emulador, predição EKF, `GyroCalibrator`, `AttitudeKalman` (roll/pitch) |
| **Control Loop** | 20 Hz | Arbitragem (manual > missão > dock > legado), executor → setpoint, segurança |
| **WebSocket Handler** | por conexão | Comandos do frontend; sub-task `_telemetry_sender` @20 Hz por cliente |

```
┌──────────────┐     ┌──────────────┐     ┌──────────────┐
│  WebSocket   │     │   Vision     │     │   Serial     │
│   Handler    │     │    Loop      │     │    Loop      │
└──────┬───────┘     └──────┬───────┘     └──────┬───────┘
       │ last_command       │ correct_apriltag   │ enc + gyro(calibrado)
       │                    │ (suprimido no dock)│ ekf.predict()
       └────────────────────┼────────────────────┘
                            ▼
                   ┌─────────────────┐
                   │  Control Loop   │
                   │  MANUAL: joy→tw │
                   │  AUTO:          │
                   │   missão ativa? │──→ SegmentExecutor
                   │   dock ativo?   │──→ TagDocker
                   │   senão         │──→ NavigationCtrl
                   │  → setpoint     │
                   └────────┬────────┘
                            │ current_setpoint
                            ▼
                   Serial Loop → ESP32
```

Modo simulação (`SIM=1`): Serial Loop e Vision Loop usam emulador e visão
sintética. Ver [`simulation.md`](./simulation.md).

## Máquina de estados de missão

Estados: `IDLE → LOAD_MAP → DRAW_TARGETS → GO_TO_PICK → AT_PICK →
GO_TO_PLACE → AT_PLACE → GO_HOME → DONE`, com ramo `FAULT` a partir de
qualquer estado ativo.

| Estado | Robô | Garra |
|---|---|---|
| GO_TO_* / GO_HOME | Navega (SegmentExecutor) | Manual (operador) |
| AT_PICK / AT_PLACE | Parado | Operador aciona + clica "continuar" |
| FAULT | Telemetria registra a falha e as rodas zeram no tick do fault, mas o control loop não bloqueia AUTOMATICO: com a missão inativa, o ramo cai no dock-to-tag (ou legado) no tick seguinte — operador deve resetar a missão ou mudar de modo. | — |

Prioridade de alvos: argumento explícito (UI/REST) > defaults `MISSION_DEFAULT_PICK_ID="L3"` / `MISSION_DEFAULT_PLACE_ID="R1"` (hardcoded em `config.py`) > sorteio com `_seed=42` (hardcoded em `mission_sm.py`; o `MISSION_SEED` de `config.py` não é lido pela SM).

Implementação: `pi/app/mission/mission_sm.py`. Ver [`mission.md`](./mission.md).

## Dock-to-tag (modo padrão de AUTOMATICO sem missão)

Desde 2026-07-07 (`DOCK_TO_TAG_ENABLED = True` hardcoded), o ramo AUTOMATICO
sem missão usa o `TagDocker` em vez do navegador legado. O legado só roda se
o dock for desligado em runtime (`POST /dock/disable`).

O dock vê 1 tag, planeja **uma vez** com Manhattan no **frame do robô** (não
nos eixos do mapa — escolha estranha, mas funciona sem mapa), e executa os
segmentos pelo EKF. Detalhes em [`dock-to-tag.md`](./dock-to-tag.md).

Diferença da missão: o dock usa `_plan_steps()` (Manhattan relativo ao robô:
avança no heading, gira ±90°, avança, gira final), enquanto a missão usa
`plan_route()` (A*/Manhattan nos eixos do mapa).

Durante dock ativo, correções EKF por tag são **suprimidas** (`vision_loop.py`
pula `correct_apriltag()` quando `state.docker.is_docking`) — a execução é
pura odometria. Essa é outra escolha estranha: foi feita para evitar saltos de
pose durante a aproximação curta, mas significa que a precisão depende da
qualidade da predição.

Estados: `SEEKING → DOCKING → DONE` (+ `FAULT` por timeout). Em `DONE` o docker
continua observando: se uma nova detecção gerar um alvo a mais de 0,10 m
(`_REPLAN_MIN_TRAVEL_M` — tag movida, tag nova ou robô deslocado), re-planeja
automaticamente.

## Malha em cascata de controle

```
Pose alvo (mapa)
      ↓
PathPlanner → [FORWARD, TURN, ...]
      ↓
SegmentExecutor  ─── malha EXTERNA (Pi ~20 Hz)
  pose EKF → (v, ω) → (ω_esq, ω_dir)
      ↓ setpoint serial
ESP32 PID por roda ─── malha INTERNA (~100 Hz)
  ω_medido (encoder) → duty PWM → motor
```

- **Externa:** posição e heading → velocidades de roda desejadas
- **Interna:** velocidade de roda → PWM (não duplicar PID no Pi)

Detalhes em [`navigation.md`](./navigation.md).

## EKF 2D — [x, y, θ]

EKF para pose no plano. O `AttitudeKalman` (1D, roll/pitch) continua rodando
em paralelo no `serial_loop.py` para a telemetria da UI — são filtros separados.

| Fase | Fonte | Módulo |
|---|---|---|
| Predição | Encoders + giroscópio Z (pós-`GyroCalibrator`: bias, auto-orientação de eixo) | `serial_loop.py` → `ekf.predict()` |
| Correção | AprilTag (PnP → pose no mundo) | `vision_loop.py` → `ekf.correct_apriltag()` |
| Gating | Distância de Mahalanobis > 3.0 descartada | `ekf.py` |

Fusão gyro/odom: `omega = 0.7*gyro + 0.3*odom` (hardcoded `alpha_gyro=0.7` em
`ekf.py`, não vem de `config.EKF_*` — esses existem em `config.py` mas não são
lidos pelo EKF; valores duplicados).

Q é dinâmico: escala com velocidade e giro via `speed_factor`/`turn_factor`/`dt`.
R é escalonado pela `quality` da detecção (mín. 0.1). Covariância 3×3, não 2×2.

Exceção durante dock: `vision_loop.py` **não** chama `correct_apriltag()` quando
`state.docker.is_docking` — execução em pura odometria.

Estado em SI (m, rad). Telemetria exporta elipse 2D para a UI.

## Modelo de mundo paramétrico

A arena não é hardcoded — é carregada de arquivo JSON em `pi/maps/`:

```
pi/maps/*.json  →  ArenaMap (Pydantic)  →  WorldModel
```

Expõe dimensões da arena, tags (`position_id`, pose), `start_pose`, `home_pose`
e grafo opcional de waypoints. Trocar mapa = trocar arena/missão sem alterar
código.

- Schema: `pi/app/world/map_schema.py`
- Fachada: `pi/app/world/world_model.py`
- Documentação: [`maps.md`](./maps.md)

## Decisões de projeto

- Arquitetura hierárquica de 3 camadas: Frontend → Pi → ESP32.
- Raspberry Pi em Python. Backend assíncrono com FastAPI + `asyncio`,
  3 loops no startup + handler WebSocket por conexão.
- ESP32 em C++ (Arduino, PlatformIO). PID a ~100 Hz e determinismo de tempo real.
- Frontend em React + Vite (navegador do celular).
- Frontend ↔ Pi: WebSocket full-duplex sobre Wi-Fi local.
- Pi ↔ ESP32: UART USB, 115200 baud, 20 Hz, framing JSON + CRC8(hex) + `\n`.
- Garfo sempre manual — sem atuação autônoma no protocolo serial.
- Monorepo com três apps (`pi/`, `firmware/`, `frontend/`) + `docs/` + `scripts/`.
- Mapas em JSON — arena paramétrica, não hardcoded.

## Parâmetros em aberto

Não atribuir valores por conta própria. Cada parâmetro pendente existe como
constante nomeada com placeholder marcado e `TODO(equipe)`; alguns já foram
definidos e estão indicados abaixo.

| Parâmetro | Onde mora | Observação |
|---|---|---|
| Massa real do pallet | `pi/app/config.py` | Intro do relatório diz ~1 kg, mas o cálculo do garfo usou 0,1 kg. Inconsistência aberta. |
| Versão do motor do garfo (torque) | `config` + docs | Depende da massa real; versão 40 rpm pode estar subdimensionada. |
| Modelo do Raspberry Pi | este arquivo | Decide FPS de visão e orçamento de energia. `TODO(equipe)`. |
| `L` (distância entre rodas), `r` (raio da roda) | `pi/app/config.py` | Cinemática diferencial. |
| Ganhos PID (`Kp, Ki, Kd`) por roda | `firmware/src/config.h` | Sintonia inicial Ziegler-Nichols, depois empírica. |
| Ganhos malha externa (`NAV_K_DIST`, `NAV_K_HEADING`) | `pi/app/config.py` | Valores atuais 1,5 e 2,5; sintonia fina pendente. |
| Ganhos navegação legado (`Kz, Kx, Kp_pitch`) | `pi/app/config.py` | Modo automático reativo. |
| `Zref` (distância de parada) | `pi/app/config.py` | ~15 cm provisório; depende do comprimento do garfo. |
| Ruído EKF (`EKF_Q_*`, `EKF_R_*`) | `pi/app/config.py` | Fusão odometria + tag. Não conectados: o EKF usa atributos de classe hardcoded em `ekf.py` (`Q_BASE_XY=0.001`, `Q_BASE_THETA=0.002`, `R_XY=0.01`, `R_THETA=0.05`); os `EKF_*` de config são duplicatas não lidas. |
| Intrínsecos da câmera (`fx, fy, cx, cy`) | `pi/calibracao/camera_intrinsics.json` | Definidos: recalibração de 2026-07-07 (1280×720). Ver [`camera-calibration.md`](./camera-calibration.md). |
| Tamanho físico da AprilTag | `pi/app/config.py` | Necessário para a pose. |
| Offset extrínseco câmera→garfo | `pi/app/config.py` + docs | Alinhar a câmera ≠ alinhar o garfo. |
| Timeout "manter último setpoint" (ESP32) | `firmware/src/config.h` | Definido: `SETPOINT_TIMEOUT_MS = 200` ms. |
| `MISSION_RESUME_TRIGGER` | `pi/app/config.py` | Botão vs. fim-de-curso. |
| Access Point Wi-Fi (Pi ou roteador) | este arquivo | Afeta o RTT alvo < 170 ms. `TODO(equipe)`. |

### Definições pendentes de infraestrutura (`TODO(equipe)`)

- **Modelo do Raspberry Pi:** a definir. Impacta FPS de visão e energia.
- **Access Point Wi-Fi:** a definir se o AP é o próprio Pi ou um roteador externo.
  Meta de RTT comando→ação < 170 ms.

## Restrições de engenharia a respeitar

- A cinemática assume rodas sem escorregamento; a odometria por encoder degrada
  se patinar.
- Estimar pitch de uma única tag pequena tem ambiguidade de pose conhecida.
- A tag pode sair do FOV ou sair de foco na reta final (Z pequeno); missão e
  dock ignoram tag-loss (bypassam segurança), legado para em `PARADO`.
- Em modo automático legado, `ω = Kx·X + Kp·Pitch` pode acoplar os dois termos;
  `NavigationController` tem fases (COARSE_ALIGN, APPROACH, FACE, RETREAT) com
  fallback de oscilação, não a fórmula simples — ver `navigation.py`.
- O canal de comando (WebSocket) tem watchdog de 400 ms: se cair no modo
  manual com o robô andando, o robô para (mas missão ativa anula o efeito).
- Navegação por mapa depende de correções EKF por tag — deriva de odometria
  entre detecções é esperada.

## Estado seguro / watchdogs

O sistema inicia em `PARADO` (`state_machine.py`). Transições de segurança
usam um **latch**: `PARADO` por segurança trava até `acknowledge()` explícito
(comando MANUAL ou AUTOMATICO via WebSocket). Exceção: missão e dock ativos
chamam `acknowledge()` automaticamente no tick seguinte.

Razões de parada expostas na telemetria (`parado_reason`): `tag_loss`,
`command_watchdog`, `ws_disconnect`, `serial_loss`, `force_stop`.

| Watchdog | Valor | Condição | Efeito |
|---|---|---|---|
| **Setpoint ESP32** | `SETPOINT_TIMEOUT_MS = 200` ms | Sem setpoint novo | ESP32 zera motores |
| **Comando (Pi)** | `COMMAND_WATCHDOG_MS = 400` ms | MANUAL + rodas em movimento + sem comando novo | Pi força `PARADO` |
| **Serial loss (Pi)** | `SERIAL_LOST_FRAMES = 5` (~250 ms @20 Hz) | Sem sensor frames do ESP32 | Pi força `PARADO` (defesa em profundidade) |
| **Tag-loss (Pi)** | `TAG_LOST_FRAMES = 5` (>5 frames = 6 frames ≈ 300 ms @20 Hz) | AUTOMATICO legado sem tag visível | Pi força `PARADO` |
| **Timeout de segmento** | `NAV_MAX_SEGMENT_TIME_S = 45` s | Segmento não completo | Missão → FAULT; Dock → FAULT |
| **WebSocket disconnect** | imediato | Qualquer modo | `force_stop("ws_disconnect")` |

Tag-loss e ws_disconnect são **bypassed** durante missão/dock ativos:
`control_loop.py` injeta `VisionState(detectado=True)` e auto-chama
`acknowledge()`, fazendo o robô continuar navegando sem intervenção. Isso
significa que ws disconnect só para o robô de forma confiável **sem missão
ativa** — com missão, o latch é auto-liberado no tick seguinte.

## Documentação relacionada

| Arquivo | Conteúdo |
|---|---|
| [readiness-sim-to-real.md](./readiness-sim-to-real.md) | Auditoria SIM→real |
| [simulator-to-real.md](./simulator-to-real.md) | Sim → real — o que aproveitamos |
| [hardware-deployment.md](./hardware-deployment.md) | Deploy no robô real — passo a passo |
| [verification-status.md](./verification-status.md) | Testes, bugs corrigidos, sim_sweep |
| [`mission.md`](./mission.md) | Missão pick-and-place, API, garra manual |
| [`maps.md`](./maps.md) | Formato JSON dos mapas da arena |
| [`navigation.md`](./navigation.md) | Planejador, executor, malha em cascata |
| [`dock-to-tag.md`](./dock-to-tag.md) | Aproximação a 1 tag sem missão |
| [`simulation.md`](./simulation.md) | Modo SIM=1, falhas, testes |
| [`hardware-bring-up.md`](./hardware-bring-up.md) | Pinos, energia, calibração |
| [`serial-protocol.md`](./serial-protocol.md) | Contratos de comunicação |
| [`camera-calibration.md`](./camera-calibration.md) | Calibração da câmera |

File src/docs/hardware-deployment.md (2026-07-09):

# Deploy no Robô Real — Guia Operacional

Passos para sair de `SIM=1` (simulação validada) para `SIM=0` (hardware físico):
o que já está implementado, o que falta medir e onde o código liga cada peça.

Ver também:
- [`hardware-bring-up.md`](./hardware-bring-up.md) — pinos, energia, fiação
- [`hardware-interfaces.md`](./hardware-interfaces.md) — contratos `VisionSource` / `SerialTransport`
- [`serial-protocol.md`](./serial-protocol.md) — JSON + CRC8 (fonte de verdade dos 4 contratos)
- [`camera-calibration.md`](./camera-calibration.md) — intrínsecos da câmera
- [`verification-status.md`](./verification-status.md) — o que foi testado em simulação

---

## 1. Estado atual do software

| Camada | Status | Observação |
|---|---|---|
| Lógica de controle (Pi) | Implementada | Control loop @20 Hz, EKF, missão, navegação |
| Simulação (`SIM=1`) | Validada | 210 testes pytest (209 passam, 1 pulado) + 11 vitest no frontend; sim_sweep 9/9 convergem |
| Firmware ESP32 | Implementado | PID, encoders, MPU, garfo, protocolo serial |
| Interfaces hardware Pi | Implementadas | `RealVisionSource`, `PySerialTransport` |
| Calibração câmera real | Feita (2026-07-07) | Recalibração 1280×720, fx=fy=1023,63, cx=634,08, cy=377,08 |
| Teste UART real Pi↔ESP32 | Validado (bancada 2026-07-06) | Frames, encoders, PID, watchdog |
| Mapa da arena real | Criado | `corredor_6tags_80x160.json` (80×160 cm, 6 tags, medido) |
| Parâmetros mecânicos | Provisórios | Valores em `config.py` / `config.h` — medir no robô |

A lógica (navegação, EKF, missão, máquina de estados) não muda
entre simulação e real. Só trocam as implementações injetadas em `app/main.py`.

---

## 2. Onde o hardware é ativado no código

Único ponto de troca: `lifespan()` em `pi/app/main.py`.

```
SIM=1 (simulação)                    SIM=0 (real)
─────────────────                    ──────────────
SimVisionSource                      RealVisionSource  ← OpenCV + pupil-apriltags
serial_loop_sim()                    serial_loop_real() ← PySerialTransport (UART)
FirmwareEmulator                     ESP32 via USB serial
SyntheticVision                      Câmera física
SimWorld                             Arena física + mapa JSON medido
```

Os 3 loops asyncio + WebSocket handler sobem em ambos os modos:

| Tarefa | Arquivo | Função |
|---|---|---|
| WebSocket Handler | `tasks/websocket_handler.py` | Comandos do operador, telemetria @20 Hz |
| Vision Loop | `tasks/vision_loop.py` | Detecção AprilTag → EKF |
| Serial Loop | `tasks/serial_loop.py` | Setpoint ↔ sensores @20 Hz |
| Control Loop | `tasks/control_loop.py` | Missão/navegação → setpoint @20 Hz |

Se câmera ou serial falharem no boot real, a app continua (log de erro) — útil para
bring-up parcial, mas missão autônoma exige ambos funcionando.

---

## 3. Fluxo de dados no hardware real

```
┌─────────────┐  ws://Pi:8000/ws   ┌──────────────────────────────────────┐
│  Celular    │◄──────────────────►│  Raspberry Pi                        │
│  (React)    │  comando + telem.  │                                      │
└─────────────┘                    │  Control Loop → current_setpoint     │
                                   │       ▲                              │
                                   │  Vision Loop ← câmera USB            │
                                   │       │ correct_apriltag (EKF)       │
                                   │  Serial Loop ↔ UART                  │
                                   └───────────────┬──────────────────────┘
                                                   │ /dev/ttyUSB0 @115200
                                                   │ JSON+CRC8+\n @20 Hz
                                                   ▼
                                   ┌──────────────────────────────────────┐
                                   │  ESP32                               │
                                   │  PID 100 Hz → PWM → L298n → motores  │
                                   │  Encoders + MPU-6050 → frame sensores│
                                   └──────────────────────────────────────┘
```

### O que o Pi envia ao ESP32 (contrato 3 — setpoint)

```json
{"w_esq": 0.0, "w_dir": 0.0, "garfo": "parar"}
```

| Campo | Unidade | Origem no Pi |
|---|---|---|
| `w_esq`, `w_dir` | rad/s | Control loop → cinemática / segment executor |
| `garfo` | `"subir"` \| `"descer"` \| `"parar"` | Comando WebSocket do operador (sempre manual) |

Enviado por `PySerialTransport.send_setpoint()` → `encode_setpoint()` em `comms/protocol.py`.

### O que o ESP32 devolve ao Pi (contrato 4 — sensores)

```json
{"enc": {"esq": 0.0, "dir": 0.0}, "mpu": {"ax":..,"ay":..,"az":..,"gx":..,"gy":..,"gz":..,"temp_c":..}, "bms": null}
```

| Campo | Unidade | Uso no Pi |
|---|---|---|
| `enc.esq`, `enc.dir` | rad/s | EKF predict + telemetria |
| `mpu.*` | m/s², °/s, °C | Kalman roll/pitch + EKF gyro Z |
| `bms` | null ou `{cel, i_a, temp_c}` | Telemetria (BMS ainda não integrado no firmware) |

Lido por `PySerialTransport.read_sensors()` → `SensorsFrameDecoder` → `serial_loop_real()`.

### O que a câmera fornece (interno — não vai na serial)

| Saída | Tipo | Uso |
|---|---|-----|
| `VisionState` | z_cm, x_cm, pitch_deg | Telemetria + navegação legado |
| `TagObservation[]` | posição relativa + yaw | Correção multi-tag no EKF |

Implementado em `RealVisionSource` (`tasks/vision_loop.py`).

> O que provavelmente vai mudar no hardware real:
>
> - Intrínsecos da câmera (`fx, fy, cx, cy`) — recalibrados em 2026-07-07 (1280×720); refazer se a câmera for remontada
> - Offset câmera→garfo — erro sistemático de posicionamento se não medido; medido 2026-07-07, revalidar após remontagens
> - Ganhos PID (`config.h`) — sintonia Ziegler-Nichols no chão
> - Q/R do EKF — ruído real ≠ simulado; os valores efetivos são atributos da
>   classe `PoseEKF` em `pi/app/control/ekf.py` (os `EKF_Q_*`/`EKF_R_*` de
>   `config.py` não estão conectados à classe)
> - Ganhos navegação (`NAV_*`) — dinâmica real, inércia, patinagem
> - `ENCODER_PPR`, `WHEEL_RADIUS`, `WHEELBASE` — medição mecânica
> - FOV/alcance da câmera — validar vs. `SIM_VISION_*` da simulação
> - Unidade de `bms.cel` — marcado `TODO(equipe)` (provavelmente V por célula)
> - Convenção de `yaw_rad` em `pose.py` — validar contra frame real da câmera

---

## 4. Passo a passo no robô (ordem obrigatória)

### Fase A — Montagem elétrica (sem energizar motores)

1. Conferir mapa de pinos em [`hardware-bring-up.md`](./hardware-bring-up.md)
   (ESQ=27/26/25, DIR=12/14/13 — conferido na bancada 2026-07-06: os canais
   A/B do L298n estavam trocados na fiação em relação ao rótulo M2/M3 do
   `Testes_eletronica.ino`, remapeado por software no `config.h` —, garfo=18/19/5,
   ENC-ESQ=23/15 — refiado 2026-07-06, era 34/35 —, ENC-DIR=32/33).
2. GND comum: fonte 12 V, L298n ×2, ESP32, Pi, MPU-6050.
3. Remover jumpers ENA/ENB dos dois L298n.
4. Level shifter nos encoders NXT se saída > 3,3 V (medir com multímetro).
5. Encoders sem pull-up externo: os pinos atuais (23/15 e 32/33) têm pull-up
   interno (`INPUT_PULLUP`). GPIO 34/35 ficaram livres (refiado 2026-07-06 —
   sobrecontavam por ruído; se reutilizados, exigem pull-up externo).
   Não colocar pull-up no GPIO 12 (strapping).
6. Fim-de-curso garfo: desabilitados (-1 em `config.h` — chaves não montadas;
   garfo nunca bloqueia por limite). Ao instalar, usar GPIOs livres — GPIO 5 agora
   é o PWM do garfo.
7. MPU-6050: SDA=21, SCL=22, endereço 0x68.

### Fase B — Firmware ESP32 (isolado)

```bash
cd src/firmware
pio run --target upload
pio device monitor -b 115200
```

Validar:
- [ ] Frames de sensores a ~20 Hz (JSON+CRC8)
- [ ] Girar roda manualmente → `enc.esq`/`enc.dir` mudam de sinal
- [ ] Inclinar chassi → `mpu.ax/ay/az` respondem. Parado, `|az| ≈ 9.8–11`;
      neste chassi `az` é negativo (~-11, MPU montado com z para baixo) —
      esperado, o `GyroCalibrator` detecta eixo/sinal
- [ ] Enviar setpoint de teste um lado por vez (`--w-esq X --w-dir 0`,
      depois o inverso) → gira a roda certa, para frente. O teste conjunto
      mascara canais A/B trocados (foi o caso da placa, corrigido 2026-07-06)
- [ ] Desconectar serial → motores param em ~200 ms (`SETPOINT_TIMEOUT_MS`)

### Fase C — Calibração mecânica

Medir e atualizar antes de confiar na odometria/EKF:

| Parâmetro | Arquivo | Como medir |
|---|---|---|
| `WHEEL_BASE_L_CM` | `pi/app/config.py` | Centro eixo esq → centro eixo dir |
| `WHEEL_RADIUS_R_CM` | `pi/app/config.py` | Diâmetro roda ÷ 2 |
| `ENCODER_PPR` | `firmware/src/config.h` + `config.py` | 1 volta manual → ~1440 contagens (x4; validado 2026-07-06) |
| `EMU_FORK_MAX_HEIGHT` | `pi/app/config.py` | Curso vertical do garfo |
| `PALLET_MASS_KG` | `pi/app/config.py` | Balança |
| `APRILTAG_SIZE_CM` | `pi/app/config.py` | Paquímetro na tag impressa |
| `CAMERA_TO_FORK_OFFSET_CM` | `pi/app/config.py` | Posição relativa câmera ↔ garfo |

Espelhar `WHEELBASE_M`, `WHEEL_RADIUS_M` em `config.py` (derivados automaticamente).

### Fase D — Calibração câmera

Concluída em 2026-07-07 (recalibração da câmera nova, remontada com tilt de 30°):
1280×720, fx=fy=1023,63, cx=634,08, cy=377,08 em `pi/calibracao/camera_intrinsics.json`.
Se a câmera for trocada ou remontada, repetir:

1. Seguir [`camera-calibration.md`](./camera-calibration.md).
2. Preencher `pi/calibracao/camera_intrinsics.json` com `fx, fy, cx, cy` reais.
3. Confirmar família `tag25h9` e tamanho físico da tag.

Com os valores em `null`, `RealVisionSource` falha no boot se `REQUIRE_CAMERA_CALIBRATION=1`
(padrão). Para teste sem calibração: `REQUIRE_CAMERA_CALIBRATION=0` (pose imprecisa).

### Fase E — Mapa da arena real

1. Medir arena com fita métrica (origem = canto inferior esquerdo).
2. Posicionar tags: `(x_m, y_m, yaw_deg)` + `position_id` (ex.: "L1", "P3").
3. Copiar template de `pi/maps/corredor_pequeno.json` e ajustar.
4. Validar: `python3 -c "from app.world.map_schema import load_map; load_map('maps/seu_mapa.json')"`

### Fase F — Backend Pi em modo real

Criar `src/.env`:

```bash
SIM=0
PI_HOST=0.0.0.0
PI_PORT=8000
SERIAL_PORT=/dev/ttyUSB0      # ou /dev/ttyACM0 — ls /dev/tty*
SERIAL_BAUDRATE=115200
# MAP= no .env NÃO é lido; mapa padrão hardcoded (corredor_6tags_80x160).
# Trocar via POST /maps/load/{nome} ou UI.
REQUIRE_CAMERA_CALIBRATION=1
# CAMERA_INDEX é fixado no código (app/config.py, = 0) — env não tem efeito.
VITE_PI_WS_URL=ws://<IP_DO_PI>:8000/ws
```

Subir:

```bash
cd src
pip install -e ".[dev]"
./scripts/run_pi.sh
```

Smoke tests (ordem):

| # | Teste | Esperado |
|---|---|---|
| 1 | Log "Modo REAL (hardware)" | SIM=0 ativo |
| 2 | Log "Serial loop (REAL) iniciado" | UART aberta |
| 3 | Log "Detector criado com calibração" | Câmera OK |
| 4 | Telemetria WebSocket @20 Hz | `rodas`, `imu`, `visao` fluem |
| 5 | Joystick manual | Rodas giram na direção correta |
| 6 | Garfo subir/descer | Motor garfo responde. Fim-de-curso desabilitado (-1): operador solta o botão antes do fim do curso |
| 7 | Desconectar USB serial | Motores param em ~200 ms (`SETPOINT_TIMEOUT_MS`) |
| 8 | Modo AUTOMATICO (1 clique) | Robô navega sem streaming de comando |
| 9 | Ocultar tag | PARADO + latch; só novo comando reativa |

### Fase G — Sintonia PID (ESP32)

Procedimento em `firmware/README.md` § Ziegler-Nichols:

1. Ki=0, Kd=0; aumentar Kp até oscilar → Ku
2. Medir período Tu
3. Kp=0.6·Ku, Ki=2·Kp/Tu, Kd=Kp·Tu/8
4. Ajustar empiricamente; atualizar `firmware/src/config.h`
5. Recompilar e regravar firmware

### Fase H — Sintonia navegação + EKF

1. Confirmar `ZREF_CM=15` dá margem de frenagem (ajustar se necessário).
2. Testar aproximação reativa (modo AUTOMATICO sem missão).
3. Comparar odometria pura vs. EKF com tags visíveis.
4. Ajustar Q/R do EKF nos atributos da classe `PoseEKF`
   (`pi/app/control/ekf.py`) e `NAV_K_DIST`/`NAV_K_HEADING` em `config.py`.
5. Rodar missão em arena aberta antes de corredores.

### Fase I — Missão completa

1. Conferir o mapa ativo — o padrão hardcoded já é o `corredor_6tags_80x160`;
   para outro mapa: `POST /maps/load/<nome>`
2. Iniciar: `POST /mission/start` (ou painel Mission no frontend)
3. Robô navega até pick → para → operador usa garfo → "continuar"
4. Navega até place → operador usa garfo → "continuar"
5. Retorna home → DONE

---

## 5. O que falta implementar / definir

### Bloqueantes para operação autônoma confiável

| Item | Onde | Ação da equipe |
|---|---|---|
| Calibração câmera | `pi/calibracao/camera_intrinsics.json` | Concluída 2026-07-07 (xadrez, 1280×720); refazer se a câmera for remontada |
| Mapa arena real | `pi/maps/*.json` | Criado (`corredor_6tags_80x160.json`); revalidar medidas na arena |
| Medição L, r, PPR | `config.py` + `config.h` | Medir no chassi |
| Offset câmera→garfo | `config.py` | Medido 2026-07-07; validar com fita métrica |
| Teste UART real | campo | Validado na bancada 2026-07-06 (frames, encoders, PID, watchdog) |
| Sintonia PID | `config.h` | Ziegler-Nichols no hardware |

### Definições de infraestrutura (não bloqueiam código)

| Item | Impacto | Decisão pendente |
|---|---|---|
| Modelo Raspberry Pi | FPS visão, energia | Pi 4/5 recomendado para 720p @ 20 Hz |
| Access Point Wi-Fi | RTT < 170 ms | Pi como AP vs. roteador externo |
| Massa real do pallet | Motor garfo | 0,1 kg vs ~1 kg — inconsistência aberta |
| `MISSION_RESUME_TRIGGER` | UX missão | Botão "continuar" (default) vs. fim-de-curso |
| Unidade `bms.cel` | Telemetria bateria | Confirmar V por célula |
| Integração BMS digital | Firmware | `main.cpp` tem TODO — BMS retorna null hoje |

### Melhorias recomendadas (pós bring-up)

- Teste E2E automatizado com WebSocket real (`httpx` + TestClient)
- Validar convenção `yaw_rad` em `pose.py` contra tags físicas
- Medir FOV real da câmera vs. `SIM_VISION_FOV_H_DEG=60°`
- Documentar mapa Wi-Fi e IP fixo do Pi para o celular

---

## 6. Interfaces — o que a equipe pode trocar sem tocar na lógica

Definidas em `pi/app/hardware/interfaces.py`:

### `VisionSource`

```python
def get_vision(self) -> VisionState
def get_all_detections(self) -> list[TagObservation]
```

- **Real:** `RealVisionSource` — OpenCV + pupil-apriltags
- **Sim:** `SimVisionSource` — geometria robô-tag
- **Substituir por:** qualquer classe que implemente os dois métodos
- **Injeção:** passar instância customizada em `main.py` no branch `SIM=0`

### `SerialTransport`

```python
async def open(self)
async def send_setpoint(self, setpoint: Setpoint)
async def read_sensors(self, timeout_s) -> list[Sensors]
async def close(self)
```

- **Real:** `PySerialTransport` — UART USB
- **Sim:** `FirmwareEmulator` via `serial_loop_sim`
- **Substituir por:** socket, CAN, mock para teste
- **Injeção:** `serial_loop_real(state, transport=MeuTransporte())`

Teste sem hardware: `pi/tests/test_hardware_interfaces.py::TestSerialLoopReal`.

---

## 7. Checklist final antes da competição / demo

```
[ ] Firmware gravado e frames @ 20 Hz no monitor serial
[ ] Encoders respondem; sentido de rotação correto
[ ] MPU retorna dados não-zero
[ ] Garfo sobe/desce (fim-de-curso desabilitado — operador controla o curso)
[ ] camera_intrinsics.json preenchido
[ ] Mapa JSON da arena validado
[ ] SIM=0 sobe sem erro fatal
[ ] Joystick manual OK
[ ] AUTOMATICO converge em frente à tag (Z ≈ 15 cm)
[ ] Perda de tag → PARADO latched
[ ] Watchdog do ESP32 OK (motores param ~200 ms sem setpoint)
[ ] Missão pick-place completa em arena real
[ ] Frontend conecta via Wi-Fi (VITE_PI_WS_URL correto)
[ ] Parâmetros TODO(equipe) revisados e confirmados
```

---

## 8. Comandos de referência rápida

```bash
# Verificação completa (simulação)
cd src && bash scripts/verify.sh

# Simulação + dashboard
SIM=1 ./scripts/run_pi.sh
cd frontend && npm run dev    # http://localhost:5173/demo

# Hardware real
SIM=0 ./scripts/run_pi.sh

# Testes
cd src && python3 -m pytest pi/tests/ -v
cd src && python3 pi/tests/sim_sweep.py

# Gravar firmware
cd src/firmware && pio run -t upload
```

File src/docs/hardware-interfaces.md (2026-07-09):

# Encaixes de hardware (SIM ↔ real)

A lógica (navegação, EKF, missão, máquina de estados) é a mesma em simulação e
no robô real. O que muda é só a implementação injetada em `app/main.py`, escolhida
por `config.SIM`. Dois encaixes, definidos como `Protocol` em
[`app/hardware/interfaces.py`](../pi/app/hardware/interfaces.py).

| Encaixe | SIM | Real |
|---|---|---|
| `VisionSource` | `SimVisionSource` (visão sintética) | `RealVisionSource` (OpenCV + pupil-apriltags) |
| `SerialTransport` | `FirmwareEmulator` via `serial_loop_sim` | `PySerialTransport` (UART) |

Tipos de dados trocados: `VisionState`, `Setpoint`, `Sensors` em `app/models.py`;
`TagObservation` (detecção relativa p/ o EKF) em `app/hardware/interfaces.py`.

---

## 1. Visão — `VisionSource`

```python
def get_vision(self) -> VisionState          # pose da tag mais próxima (z_cm, x_cm, pitch_deg)
def get_all_detections(self) -> list[TagObservation]   # todas as tags p/ fusão no EKF
```

A `RealVisionSource` já está implementada. O que a equipe precisa fechar:
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

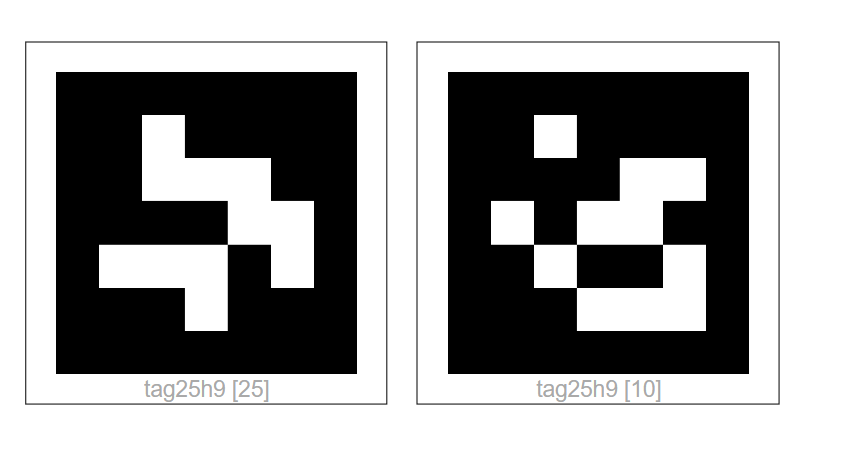
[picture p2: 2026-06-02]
images/april_tags_25h9.png

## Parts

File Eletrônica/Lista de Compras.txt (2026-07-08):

lista de compras:

3 - Chave Micro Switch KW11-7-2 3T - Com Rolete - vai comprar
1 - MPU-6050 - já temos

Substituídos por um lm2596 
{
1 - MP2307
1 - AMS1117
}

1 - JGY-370 12V DC Worm Gear Motor - vai comprar
1 - Cartão de Memória 16GB Ultra MicroSDHC UHS-I com Adaptador - vai comprar
1 - BMS 3S 30A - vai comprar

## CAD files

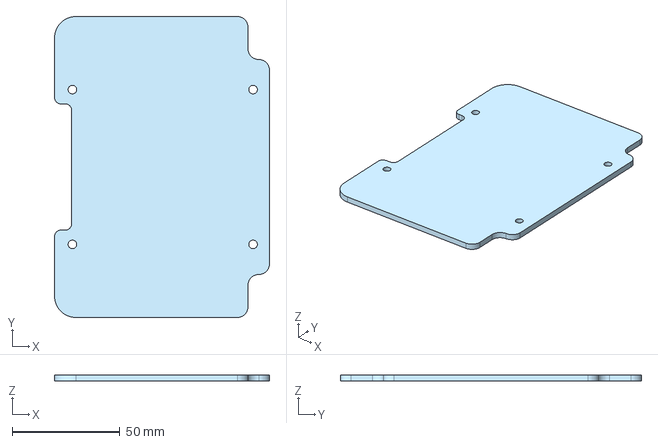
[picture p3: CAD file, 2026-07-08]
Eletrônica/Caixa_eletrônicos/V2/Caixa-V2-andar 2,3,4.step
100.0 x 140.0 x 3.00 mm

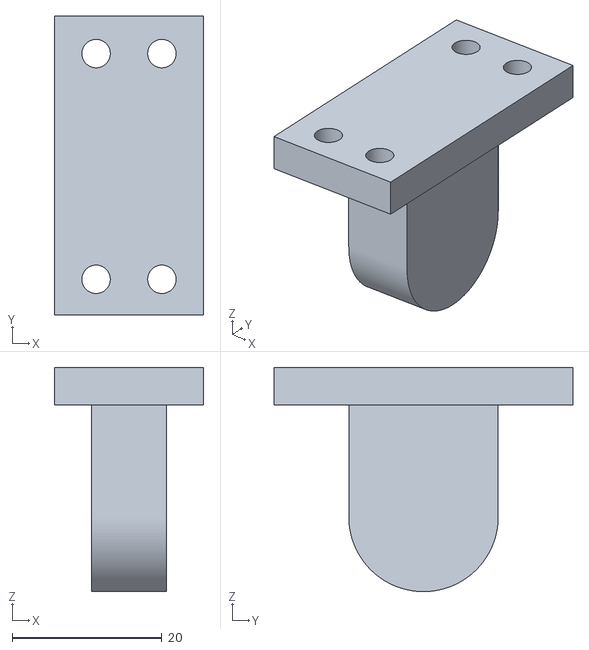
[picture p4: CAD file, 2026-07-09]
modelagem_3D/Polia Direita.stl
20.0 x 40.0 x 30.0

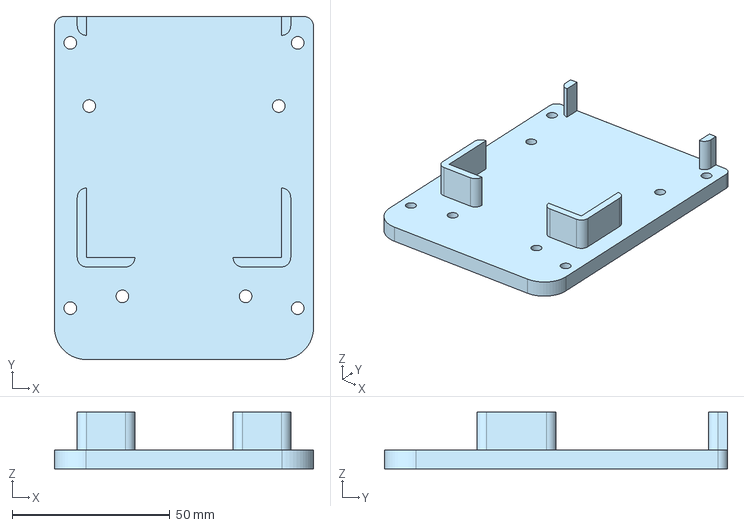
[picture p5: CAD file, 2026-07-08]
Eletrônica/Caixa_eletrônicos/V2/Caixa-V2-Andar 1.step
82.0 x 108.6 x 18.0 mm

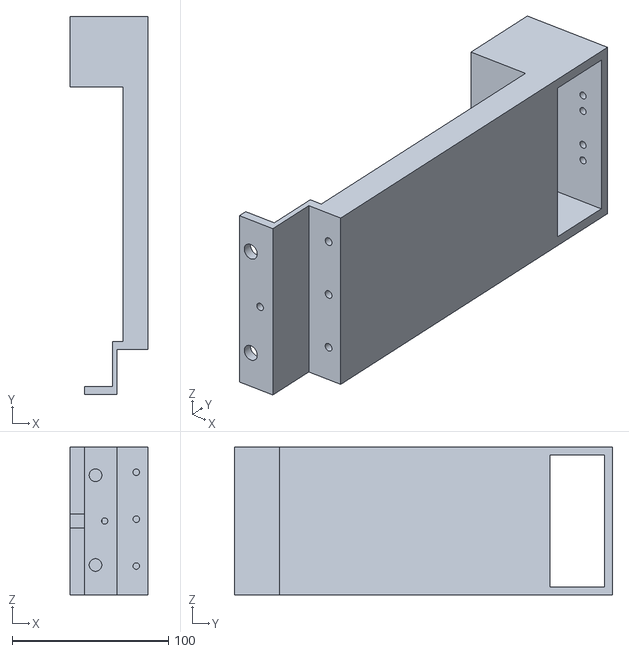
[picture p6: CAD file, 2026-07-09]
modelagem_3D/Suporte.stl
50.0 x 241.8 x 94.4

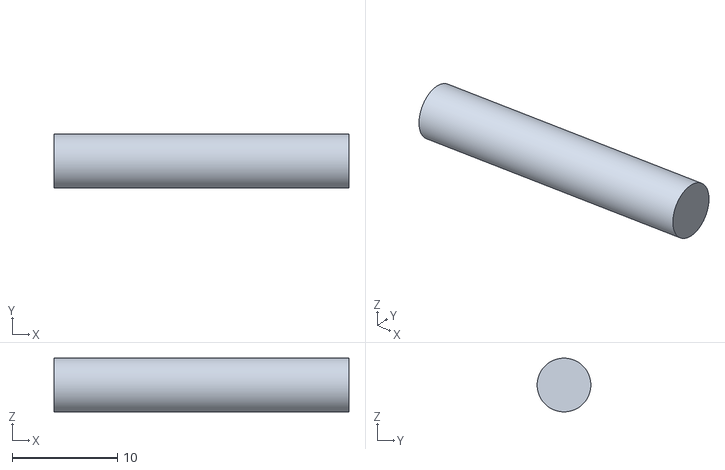
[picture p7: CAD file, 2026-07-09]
modelagem_3D/Eixo.stl
28.0 x 5.10 x 5.10

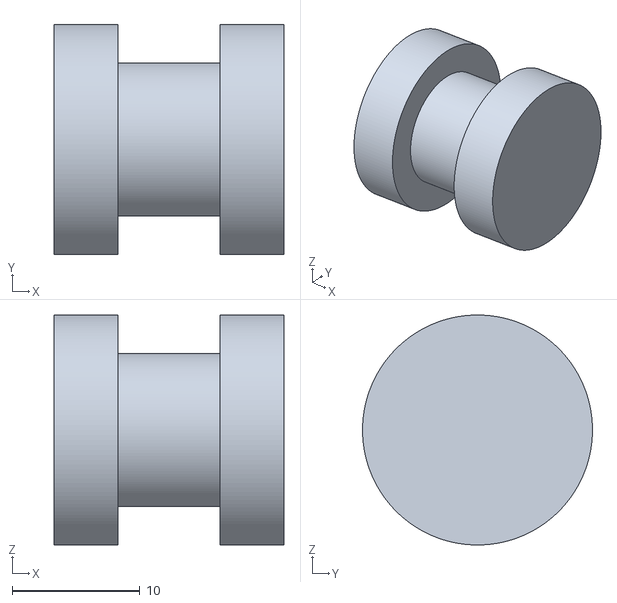
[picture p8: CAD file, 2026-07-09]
modelagem_3D/Carretel.stl
18.0 x 18.0 x 18.0

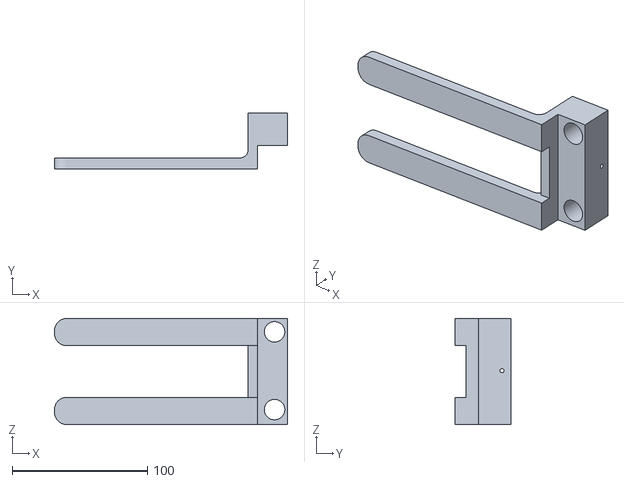
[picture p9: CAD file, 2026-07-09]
modelagem_3D/Garfo.stl
172.1 x 41.0 x 78.4

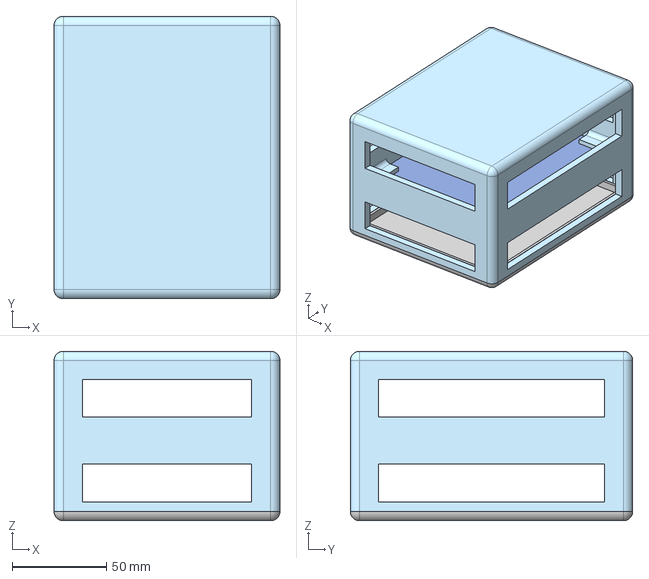
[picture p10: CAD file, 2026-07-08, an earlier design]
Eletrônica/Caixa_eletrônicos/V1/Caixa-V1.step
120.0 x 150.0 x 90.0 mm

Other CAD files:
modelagem_3D/Polia Esquerda.stl
Eletrônica/Caixa_eletrônicos/V1/Caixa-V1.x_t
Eletrônica/Caixa_eletrônicos/V2/Caixa-V2-Andar 1.x_t
Eletrônica/Caixa_eletrônicos/V2/Caixa-V2-andar 2,3,4.x_t

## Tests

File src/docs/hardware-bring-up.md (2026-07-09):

# Hardware Bring-Up

Fontes: `firmware/src/config.h`, `firmware/README.md`, `pi/app/config.py`.

Guia de montagem, energização e calibração do hardware físico da empilhadeira.
Siga a ordem das seções — energizar motores antes de validar níveis lógicos
pode danificar GPIOs ou drivers.

## Checklist Rápido

- [ ] Fonte 12 V dimensionada para 3 motores + ESP32/Pi
- [ ] GND comum entre fonte, L298n, ESP32 e Pi
- [ ] Jumpers ENA/ENB removidos nos dois L298n
- [ ] Level shifter nos encoders NXT (se saída 5 V)
- [ ] Encoders nos GPIOs 23/15 (esq) e 32/33 (dir) — todos com pull-up interno (`INPUT_PULLUP`); nenhum pull-up externo necessário (refiado 2026-07-06: 34/35 ficaram livres)
- [ ] Sem pull-up externo no GPIO 12 (strapping — **DIR** IN1, canal A roda direita)
- [ ] MPU-6050 em 3.3 V (I2C)
- [ ] Fim-de-curso: desabilitados (-1) — operador solta o botão do garfo antes do fim do curso
- [ ] Firmware gravado e frames de sensor a 20 Hz no monitor serial
- [ ] Backend Pi com `SIM=0` recebendo telemetria
- [ ] Mapa JSON medido na arena real

---

## Mapa de Pinos do ESP32

Fonte: `firmware/src/config.h` (ESP32 DevKit V1, 30 pinos).

> Alinhado 1:1 com `Testes_eletronica.ino` (fonte da verdade da placa real).
> Os nomes entre colchetes são os defines equivalentes naquele firmware de teste.

### Motores de Tração — L298n #1

| Função | GPIO | Destino |
|---|---|---|
| Motor Esq IN1 | 27 | L298n IN3 (canal B) [era M3_IN1] |
| Motor Esq IN2 | 26 | L298n IN4 (canal B) [era M3_IN2] |
| Motor Esq PWM | 25 | L298n ENB (canal B) — LEDC ch0 [era M3_EN] |
| Motor Dir IN1 | 12 | L298n IN1 (canal A) [era M2_IN1] |
| Motor Dir IN2 | 14 | L298n IN2 (canal A) [era M2_IN2] |
| Motor Dir PWM | 13 | L298n ENA (canal A) — LEDC ch1 [era M2_EN] |

> Conferido na bancada 2026-07-06: na fiação real o canal A (12/14/13)
> aciona a roda direita e o canal B (27/26/25) a esquerda — inverso do
> rótulo M2/M3 do `Testes_eletronica.ino`. Remapeado por software no `config.h`
> (`MOTOR_ESQ_INV=false`, `MOTOR_DIR_INV=true`), validado com `bench_setpoint`
> um lado por vez.

### Motor do Garfo — L298n #2

| Função | GPIO | Destino |
|---|---|---|
| Fork IN1 | 18 | L298n #2 IN1 [M1_IN1] |
| Fork IN2 | 19 | L298n #2 IN2 [M1_IN2] |
| Fork PWM | 5 | L298n #2 ENA — LEDC ch2 [M1_EN] |

### Encoders (Lego NXT 53787)

| Função | GPIO | Observação |
|---|---|---|
| Encoder Esq A | 23 | Interrupção CHANGE (decodificação x4) — refiado 2026-07-06 (era 34, que sobrecontava por ruído) |
| Encoder Esq B | 15 | Interrupção CHANGE (x4) — refiado 2026-07-06 (era 35); strapping MTDO: LOW no boot só silencia mensagens da ROM |
| Encoder Dir A | 32 | Interrupção CHANGE (x4) [era ENC1_A] |
| Encoder Dir B | 33 | Interrupção CHANGE (x4) [era ENC1_B] |
| "VCC" encoder | 2 | GPIO em OUTPUT HIGH (3,3 V) — `PIN_ENC_POWER_VCC`; LED onboard acende junto |
| "GND" encoder | 4 | GPIO em OUTPUT LOW — `PIN_ENC_POWER_GND` |

> Alimentação por GPIO: a fiação real usa GPIO 2/4 como trilhas de energia
> do encoder; `encodersBegin()` os dirige no boot (HIGH/LOW). Limite ~40 mA por
> pino — se os dois encoders alimentados por aí ficarem instáveis, mover para
> os pinos reais 3V3/GND da placa e setar `PIN_ENC_POWER_* = -1` no `config.h`.
> Se a gravação do firmware falhar, desconectar temporariamente o fio do
> GPIO 2 (strapping pin).

### Fim-de-Curso do Garfo

| Função | GPIO | Observação |
|---|---|---|
| Limite superior | -1 | Desabilitado — chave não montada; `forkAtTopLimit()` retorna sempre `false` |
| Limite inferior | -1 | Desabilitado — chave não montada; `forkAtBottomLimit()` retorna sempre `false` |

Quando as chaves forem instaladas, definir os GPIOs em `config.h` — GPIO 5
agora é o PWM do garfo e GPIO 15 é a fase B do encoder esquerdo,
então escolher outros pinos livres (ex.: 16, 17).

### I2C — MPU-6050

| Função | GPIO |
|---|---|
| SDA | 21 |
| SCL | 22 |

Endereço I2C: `0x68` (AD0 = GND).

---

## Avisos sobre Strapping Pins

GPIOs que não devem ser usados ou exigem cuidado especial:

| GPIO | Risco |
|---|---|
| 0 | Strapping — LOW no boot entra em flash mode |
| 2 | Strapping — pode afetar boot |
| 6–11 | Flash SPI interno — não usar |
| 12 | Strapping — altera tensão do flash. Usado como DIR IN1 (canal A; era rotulado ESQ/M2 até 2026-07-06): precisa estar LOW no boot. Como IN1 fica LOW em repouso, funciona — não colocar pull-up externo nele |
| 34–39 | Input-only, sem pull-up interno. 34/35 estão livres (refiado 2026-07-06 — o encoder esquerdo saiu deles); se reutilizar, pull-up externo 10 kΩ → 3V3 obrigatório |
| 5 | Strapping (HIGH no boot). Usado como PWM do garfo [M1_EN] — LEDC só ativa depois do boot |
| 15 | Strapping (MTDO). Usado como Encoder Esq B — se LOW no boot, apenas silencia as mensagens de boot da ROM; inofensivo |

Herdamos esses dois cuidados da placa real (`Testes_eletronica.ino`):

1. GPIO 12 (IN1 do canal A — hoje roda direita) é strapping pin — precisa
   estar LOW no boot ou a seleção de tensão da flash falha. IN1 idle = LOW,
   então funciona; apenas não adicionar pull-up externo nesse fio.
   (Conferido na bancada 2026-07-06: o canal A aciona a roda direita, não a
   esquerda como o rótulo M2 sugeria.)
2. GPIO 34/35 estão livres desde 2026-07-06. São input-only sem pull-up
   interno — o `pinMode(INPUT_PULLUP)` neles é silenciosamente ignorado pelo
   hardware. Por isso o encoder esquerdo, que estava nesses pinos, sobrecontava
   ~420 pulsos/volta com bordas ruidosas e foi movido para 23/15 (que têm
   pull-up interno). Se algum sinal voltar para 34/35 no futuro, pull-up
   externo 10 kΩ → 3V3 é obrigatório.

---

## Level Shifter — Encoders NXT

Os encoders Lego NXT operam tipicamente a **5 V** na saída. O ESP32 aceita
no máximo **3,3 V** nos GPIOs.

Antes de conectar, medir com multímetro a tensão nos pinos amarelo/azul
do conector NXT com o motor girando.

| Situação | Solução |
|---|---|
| Saída ≤ 3,3 V | Conexão direta (raro) |
| Saída 5 V push-pull | Level shifter bidirecional (TXS0108E, 74LVC245) ou divisor resistivo 1kΩ + 2kΩ |
| Saída open-drain fraca | Pull-up externo a 3,3 V pode ser suficiente — validar |

Fiação encoder (conector 6 pinos NXT):

```
Pin 5 (amarelo) → fase A → GPIO 23 (esq) / GPIO 32 (dir) (via level shifter se necessário)
Pin 6 (azul)    → fase B → GPIO 15 (esq) / GPIO 33 (dir)
Pin 1 (branco)  → 5 V ou 3,3 V (conforme motor)
Pin 2 (preto)   → GND
```

> Pull-ups: todos os pinos de encoder atuais (23/15 e 32/33) têm pull-up
> interno, ativado via `INPUT_PULLUP` no `encoders.cpp` — nenhum resistor
> externo é necessário. (Refiado 2026-07-06: o encoder esquerdo saiu dos GPIO
> 34/35, que são input-only sem pull-up interno e sobrecontavam por ruído.)

---

## Trilhas de Alimentação

### Fonte Principal — 12 V

Alimenta os dois módulos L298n (motores de tração + garfo). Dimensionar
corrente para pico dos três motores simultâneos (~2–3 A por canal, dependendo
da carga).

```
Fonte 12 V ──┬── L298n #1 (VCC motores)
             ├── L298n #2 (VCC garfo)
             └── Entrada do regulador buck (Pi + lógica)
GND comum ────┴── ESP32 GND, L298n GND, Pi GND, MPU GND
```

### Buck MP2307 — 5 V para Raspberry Pi

O Raspberry Pi precisa de **5 V estável @ ≥ 2,5 A**. Recomenda-se um módulo
**buck MP2307** (ou equivalente) a partir dos 12 V da bateria/fonte:

- Eficiência ~90% (vs. dissipação térmica de reguladores lineares)
- Ajustar trimpot para **5,0–5,1 V** medidos sob carga
- Adicionar capacitor eletrolítico 470–1000 µF na saída

### AMS1117-3,3 V — ESP32 e Lógica

O ESP32 opera a **3,3 V**. Módulos AMS1117-3.3 são comuns, mas têm limitações:

| Problema | Detalhe |
|---|---|
| Regulador linear | Dissipa `(Vin − 3,3 V) × I` como calor |
| Dropout ~1,1 V | A partir de 5 V USB funciona; a partir de 12 V não usar AMS1117 direto |
| Corrente máxima ~800 mA | Insuficiente se alimentar ESP32 + MPU + pull-ups de encoder |

Recomendação:

- Alimentar ESP32 via USB (5 V do buck MP2307) durante bring-up, ou
- Usar buck 12 V → 3,3 V dedicado (ex.: LM2596 ajustado, ou AMS1117 apenas
  se a entrada for 5 V regulada)

> Não alimentar o ESP32 pelo pino 5V out do L298n — tensão instável e
> sem proteção.

### Separação de Massas

Manter GND comum entre fonte, drivers, ESP32 e Pi. Evitar loops de
corrente de motor passando pelo GND do Pi — usar ponto único de estrela
próximo à fonte.

---

## Dual L298N — Três Motores

| Módulo | Canais | Motores |
|---|---|---|
| L298n #1 | A + B | Roda esquerda + roda direita |
| L298n #2 | A | Garfo (JGY-370 worm gear) |

Obrigatório: remover jumpers ENA/ENB em ambos os módulos para habilitar
controle PWM pelos GPIOs 25 (esq, ENB do L298n #1), 13 (dir, ENA do L298n #1)
e 5 (garfo, ENA do L298n #2).

PWM: 20 kHz, 8 bits (0–255 duty). Ver `LEDC_FREQ_HZ` e `LEDC_RESOLUTION_BITS`
em `config.h`.

---

## Garfo Manual + Fim-de-Curso

O garfo é sempre manual — o operador comanda via WebSocket (`garfo:
subir/descer/parar`), repassado ao ESP32 no campo `garfo` do setpoint.

### Comportamento no Firmware

- Duty fixo `FORK_DUTY = 220` (~86%) enquanto o comando estiver ativo
  (subiu de 180 na bancada 2026-07-06/07 para levantar com carga)
- Fim-de-curso (quando instalado) corta o motor localmente em ~10 ms
  (próximo ciclo PID) — hoje desabilitado com -1 em `config.h`
- Worm gear retém carga sem PWM de manutenção
- Nenhum campo extra no protocolo serial para garfo autônomo

### Fiação dos Switches

Estado atual: fim-de-curso desabilitado (`PIN_FORK_LIMIT_TOP/BOTTOM = -1`
em `config.h`). O robô ainda não tem as chaves montadas; `motors.cpp` pula o
`pinMode` e `forkAt*Limit()` retorna sempre `false` — o garfo nunca é
bloqueado por limite. Enquanto isso, o operador deve soltar o botão antes
do fim do curso mecânico.

Quando as chaves forem instaladas:

```
Switch NO (topo):   COM → GND,  NO → GPIO livre (ex.: 16)
Switch NO (base):   COM → GND,  NO → GPIO livre (ex.: 17)
INPUT_PULLUP: HIGH = livre, LOW = no limite
```

> Evitar GPIO 34–39 para os switches: são input-only sem pull-up interno,
> exigiriam pull-up externo 10 kΩ → 3V3.

> GPIO 5 não está mais disponível (é o PWM do garfo). Definir os novos
> GPIOs em `config.h` e regravar o firmware.

Se os switches forem NC, alterar `FORK_LIMIT_ACTIVE_LEVEL` para `HIGH` em
`config.h`.

---

## Transição SIM=1 → Hardware Real

### 1. Firmware

```bash
cd src/firmware
pio run --target upload
pio device monitor   # verificar frames @ 20 Hz
```

### 2. Configuração do Pi

```bash
# .env
SIM=0
SERIAL_PORT=/dev/ttyUSB0    # ou /dev/ttyACM0
SERIAL_BAUDRATE=115200
# MAP= no .env NÃO é lido — mapa padrão hardcoded. Trocar via POST /maps/load/{nome} ou UI.
```

### 3. Validar Comunicação

```bash
cd src/pi
python -m app.main
# Telemetria deve fluir; encoders respondem ao girar rodas manualmente
```

### 4. Validar Frontend

- Joystick manual move as rodas
- Garfo sobe/desce com botões
- Watchdog: desconectar USB → motores param em ~200 ms (`SETPOINT_TIMEOUT_MS`)

### 5. Calibrar e Testar Missão

- Medir arena → criar/atualizar mapa JSON
- Calibrar EKF com tags visíveis
- Rodar missão em arena aberta antes de corredores

---

## Checklist de Calibração

### Mecânica

| Parâmetro | Onde | Como medir |
|---|---|---|
| Raio da roda `WHEEL_RADIUS_R_CM` | `pi/app/config.py` | Medir diâmetro ÷ 2 |
| Distância entre rodas `WHEEL_BASE_L_CM` | `pi/app/config.py` | Centro eixo a centro eixo |
| Massa do pallet `PALLET_MASS_KG` | `pi/app/config.py` | Balança — TODO(equipe) |
| Altura máxima garfo `EMU_FORK_MAX_HEIGHT` | `pi/app/config.py` | Medir curso vertical |

### Encoders

| Parâmetro | Onde | Como validar |
|---|---|---|
| `ENCODER_PPR = 1440` | `firmware/config.h` | 1 volta manual → ~1440 contagens no monitor (10 voltas → ~14400); 360 ciclos × 4 da decodificação x4 — validado 2026-07-06 |
| Sentido dos motores | `config.h` (`MOTOR_ESQ_INV=false`, `MOTOR_DIR_INV=true`, `FORK_INV`) | Setpoint positivo → as duas rodas para frente; "subir" sobe o garfo. Validado na bancada 2026-07-06 um lado por vez (`bench_setpoint --w-esq X --w-dir 0`) — o teste conjunto mascara canais A/B trocados (com as malhas PID cruzadas, uma roda satura e a outra para, alternando o lado) |
| Sinal dos encoders | `config.h` (`ENC_ESQ_INV=true`, `ENC_DIR_INV=true`) | Roda para frente → ω positivo no monitor. Se negativo, inverter o flag (crítico: sinal errado faz o PID divergir). Validado na bancada 2026-07-06 com a decodificação x4 |
| Level shifter | Fiação | Osciloscópio/multímetro ≤ 3,3 V nos GPIOs |

### PID (Malha Interna)

| Parâmetro | Onde | Procedimento |
|---|---|---|
| Kp, Ki, Kd | `firmware/config.h` | Ziegler-Nichols (ver `firmware/README.md` §4.2) |
| `SETPOINT_TIMEOUT_MS = 200` | `firmware/config.h` | Validar watchdog desconectando USB |
| `FORK_DUTY = 220` | `firmware/config.h` | Ajustado na bancada 2026-07-06/07 (180→220 p/ levantar com carga); revalidar com o pallet real |

### Visão / AprilTag

| Parâmetro | Onde | Procedimento |
|---|---|---|
| Intrínsecos `fx, fy, cx, cy` | `pi/calibracao/camera_intrinsics.json` | Calibração xadrez — ver [`camera-calibration.md`](./camera-calibration.md) |
| Tamanho da tag `APRILTAG_SIZE_CM` | `pi/app/config.py` | Medir tag impressa com paquímetro |
| Offset câmera→garfo | `pi/app/config.py` | Medir posição relativa — medido 2026-07-07; revalidar após remontagens |
| Família `tag25h9` | fixo | Imprimir tags da família correta |

### Navegação (Malha Externa)

| Parâmetro | Onde | Procedimento |
|---|---|---|
| `NAV_K_DIST`, `NAV_K_HEADING` | `pi/app/config.py` | Sintonizar após PID interno estável |
| `NAV_POS_TOL_M`, `NAV_HEADING_TOL_RAD` | `pi/app/config.py` | Ajustar precisão de parada |
| Q/R do EKF (`Q_BASE_*`, `R_*`) | `pi/app/control/ekf.py` (atributos da classe `PoseEKF`) | Comparar odometria pura vs. com tag. Os `EKF_Q_*`/`EKF_R_*` de `config.py` existem mas não estão conectados à classe — editar o `ekf.py` |
| `MAHALANOBIS_GATE` | `pi/app/control/ekf.py` (o `EKF_MAHALANOBIS_GATE` de `config.py` também não está conectado) | Testar com blur / detecções ruins |

### Mapa

| Item | Procedimento |
|---|---|
| Dimensões da arena | Fita métrica, canto inferior esquerdo = origem |
| Posição de cada tag | (x, y) em metros + `yaw_deg` |
| Waypoints (se corredor) | Pontos nos corredores + arestas sem cruzar paredes |
| Validar JSON | `python -c "from app.world.map_schema import load_map; load_map('maps/...')"` |

---

## Troubleshooting

| Sintoma | Causa provável | Ação |
|---|---|---|
| ESP32 não grava / boot falha | GPIO 12 (**DIR** IN1, canal A) puxado HIGH no boot | Remover pull-up externo; desconectar driver ao gravar se preciso |
| Encoder sempre zero | Sem level shifter / fiação | Verificar tensão e ISR |
| Encoder sempre zero após refiação para GPIO 34/35 | 34–39 são input-only sem pull-up interno | Só se aplica se alguém religar um encoder em 34/35 (hoje livres): instalar 10 kΩ → 3V3 em cada fase. Os pinos atuais (23/15 e 32/33) têm pull-up interno |
| Motor oscila | Kp alto ou PPR errado | Ziegler-Nichols; validar PPR |
| Garfo não segura carga | Duty baixo ou motor errado | Aumentar `FORK_DUTY`; confirmar worm gear |
| Pi reinicia ao acionar motor | Fonte subdimensionada | Buck MP2307 com margem; capacitor na saída |
| ESP32 reseta com motores | Queda de 3,3 V | Separar alimentação lógica da tracionária |
| MPU retorna zeros | I2C mal conectado | Verificar SDA/SCL, endereço 0x68 |
| Tag não detectada | Intrínsecos errados / tag pequena | Recalibrar câmera; aumentar tag |

Documentação complementar: [`firmware/README.md`](../firmware/README.md).

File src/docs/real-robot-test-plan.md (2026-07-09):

# Plano de Testes no Robô Real — 3 Fases com Portões

> **Regra:** só avance de fase com a anterior 100% verde. Se algo quebrar numa
> fase, a causa está quase sempre na própria fase — as de baixo já foram validadas.
>
> - Fase 1 isola problemas de fio e configuração (mais fáceis de resolver na bancada do que no chão)
> - Fase 2 isola dinâmica e segurança com o operador no controle (só MANUAL)
> - Fase 3 liga a autonomia quando tudo abaixo já foi validado

Docs relacionados: [`hardware-bring-up.md`](./hardware-bring-up.md) (fiação/pinos),
[`hardware-deployment.md`](./hardware-deployment.md), [`camera-calibration.md`](./camera-calibration.md).

## Status — pendências (registro de 2026-07-07, fim do dia)

Feito: encoders (x4, sinais, PPR 1440, isolamento ok) · canais/sentido dos
motores (um lado por vez) · PID convergindo na bancada · watchdog serial
< 200 ms · telemetria/CRC/MPU sãos · fixes de sinal (manual + visão) no código
· v_máx medida: 24 cm/s → config 19 · raio ajustado para 2,7 cm (medição da
equipe; falta confirmar por rolagem) · tilt da câmera: 30° (remontagem
2026-07-07, 2ª vez; `pose.py` rotaciona a pose → z = distância horizontal;
1ª montagem da câmera nova media 22,7°; câmera antiga, 28,4°) · offset câmera→garfo assinado:
(0.0, -14.2, -10.0) (lente atrás da ponta do garfo → z do offset negativo;
validar com fita) · `FORK_DUTY` 180→220 (levanta com carga) · dock-to-tag e
/world-state implementados (verdes em teste de unidade).

Falta, na ordem:
- [x] Recalibrar a câmera — recalibração de 2026-07-07 feita (câmera nova,
      1280×720, fx=fy=1023,63, cx=634,08, cy=377,08; sem erro de reprojeção
      registrado)
- [ ] Validar z/x com fita métrica a 30 cm e 15 cm com a calibração nova
- [ ] 2.1 manual completo no chão (reto, ré, joystick à direita→direita,
      giro anti-horário→heading aumenta, talo baixo anotado)
- [ ] 3.1 medições restantes: raio por rolagem (confirmar o 2,7), bitola
      (+ refino pelo 360°), ω máx cronometrado (1 volta), validar o offset
      câmera→garfo assinado (-10,0), tag no paquímetro (4 cm)
- [ ] 1.4 checks 5 e 6: sinal do `x_cm` (tag à esquerda → positivo) e do
      `pitch_deg` — últimas convenções não validadas no hardware
- [ ] 1.2 check 5: sinal do `gz` no giro à mão (anotar para o EKF)
- [ ] 2.2 garfo com carga · 2.3 watchdogs andando · 2.4 odometria
      (1 m e 360°)
- [ ] Fase 3 inteira (nunca rodou no hardware): 3.2 reativa → 3.3 segurança
      → 3.4 EKF corredor → 3.4b dock → 3.5 missão 3× → 3.6 dia D

Estado consolidado (atualizado 2026-07-06):
- Mapa real: `pi/maps/corredor_6tags_80x160.json` — ok (valida no schema)
- 2026-07-06: dock-to-tag (hardcoded ligado desde 2026-07-07) + vista de cima
  no robô real — modo padrão de AUTOMATICO sem missão, que estaciona em frente
  a uma tag por segmentos (testado em unidade, não no hardware) e endpoint
  `GET /world-state` que faz a tela `/demo` desenhar o Arena no hardware
  (pose do EKF + mapa). Hardcoded ligado desde 2026-07-07; ver `docs/dock-to-tag.md`.
- Calibração: `pi/calibracao/camera_intrinsics.json` — recalibração de
  2026-07-07 feita (câmera nova, 1280×720, fx=fy=1023,63, cx=634,08,
  cy=377,08) — validar z/x com fita. A calibração antiga (câmera antiga,
  640×480, reproj 0,144 px, cx=399 anômalo) foi descartada. O JSON da 2ª cal
  não registra o reproj (`reprojection_error: null`).
- Captura deve rodar em 1280×720 (`CAMERA_FRAME_WIDTH/HEIGHT` no config)
- Pinagem firmware conferida na bancada; fim-de-curso desabilitado (-1)
- 2026-07-06: canais dos motores estavam trocados na fiação (canal A
  12/14/13 aciona a roda direita; canal B 27/26/25 a esquerda — o inverso do
  rótulo M2/M3 do `Testes_eletronica.ino`). Remapeado por software no
  `config.h`: `PIN_MOTOR_ESQ_*`=27/26/25 (`MOTOR_ESQ_INV=false`),
  `PIN_MOTOR_DIR_*`=12/14/13 (`MOTOR_DIR_INV=true`). Sintoma que isso causava:
  com as malhas PID cruzadas (cada PID lia uma roda e acionava a outra), uma
  roda saturava no máximo e a outra morria, alternando aleatoriamente o lado
  entre testes. Lição: sempre testar um lado por vez (`--w-esq X --w-dir 0`)
  — o teste com as duas rodas juntas não detecta canais trocados.
- 2026-07-06: dois bugs de sinal corrigidos no Pi — (a) modo manual:
  `joystick_to_twist` gerava ω invertido (joystick à direita virava à
  esquerda); (b) visão real: o x do frame óptico OpenCV (positivo = direita) é
  o oposto da convenção do projeto (positivo = esquerda, a do simulador/nav) —
  negado na fronteira em `pose.py`. Sem o fix (b), a autonomia viraria para
  longe da tag. Validar (b) no 1.4 com a tag deslocada.
- 2026-07-06: encoders funcionando (alimentação via GPIO 2 = VCC / GPIO 4 =
  GND, dirigidos pelo `encodersBegin()`; lados esq↔dir corrigidos no `config.h`:
  ESQ=23/15, DIR=32/33 — o esquerdo foi refiado no mesmo dia de 34/35 para
  23/15, pois 34/35 são input-only sem pull-up interno e sobrecontavam ~420
  pulsos/volta por ruído). Decodificação agora é a completa x4 (CHANGE nas
  duas fases, tabela de transição em `encoders.cpp`) → `ENCODER_PPR=1440`;
  sinais validados na bancada (`ENC_ESQ_INV=true`, `ENC_DIR_INV=true`).
  O firmware é sempre malha fechada (PID ativo; a antiga flag `OPEN_LOOP`
  não existe mais no código).

---

## FASE 0 — Setup e topologia

### As duas topologias (não misturar)

**Modo DEV — durante o desenvolvimento (Mac + Pi):**

```
Mac (você)                         Raspberry Pi (no robô)
├── edita o código                 ├── backend SIM=0 (./scripts/run_pi.sh)
├── serve o frontend               ├── câmera USB
│   (npm run dev, porta 5173)      └── UART ↔ ESP32
└── git push ──────► git pull no Pi + reiniciar backend
Celular/navegador → http://<IP_DO_MAC>:5173  ──WebSocket──► ws://<IP_DO_PI>:8000/ws
```

- No `.env` do Mac: `VITE_PI_WS_URL=ws://<IP_DO_PI>:8000/ws` (obrigatório
  neste modo — a página vem do Mac, então o fallback de mesmo-host apontaria
  para o Mac, errado).
- O dev server já expõe na rede (`host: true` no vite.config) e recarrega a
  cada edição — ideal para iterar.
- Sincronizar código com o Pi: `git push` no Mac → `git pull` no Pi → reiniciar
  o backend. (Alternativa rápida sem commit:
  `rsync -av --exclude .venv --exclude node_modules src/ pi@<IP>:~/Empilhadeira/src/`)
- Todos os passos de firmware/bancada/câmera (1.2–1.4) rodam no Pi via SSH
  — o ESP32 e a câmera estão plugados nele.

**Modo OPERAÇÃO — demo/desafio (só Pi, Mac desligado, sem Node no Pi):**

```
Mac (antes):  cd src/frontend && npm run build
              rsync -av dist/ pi@<IP>:~/Empilhadeira/src/frontend/dist/
Pi (sozinho): ./scripts/run_pi.sh   ← o backend serve o frontend buildado
Celular     → http://<IP_DO_PI>:8000/   (tudo numa porta; WebSocket resolve sozinho)
```

O backend detecta `frontend/dist/` no boot e serve o app na própria porta 8000
(log: `Frontend estático montado de ...`). Não precisa de Node/npm no Pi —
o build é feito no Mac e só os arquivos estáticos são copiados.

Use DEV para os testes das Fases 1–3 enquanto itera; valide o modo OPERAÇÃO
inteiro pelo menos uma vez antes do dia do desafio (item 3.6).

### Setup único do Raspberry Pi

O Pi grava o firmware do ESP32 (USB), roda o backend e a câmera. Você opera
o Pi por SSH.

```bash
# 1. Código
git clone <url-do-repo> && cd Empilhadeira/src        # ou git pull

# 2. Python + dependências do backend
python3 -m venv .venv && source .venv/bin/activate
pip install -e ".[dev]"

# 3. PlatformIO (para gravar o ESP32 a partir do Pi)
pip install platformio
# A primeira compilação baixa o toolchain ESP32 inteiro (centenas de MB).
# Precisa de internet e demora vários minutos no Pi — é uma vez só.

# 4. Permissões de serial e câmera
sudo usermod -aG dialout,video $USER
# Deslogar e logar de novo (grupo só vale em sessão nova de SSH)

# 5. Descobrir porta do ESP32 e IP do Pi (anote os dois)
ls /dev/ttyUSB* /dev/ttyACM*
hostname -I

# 6. Criar o .env do backend (uma vez; precisa existir antes da câmera, item 1.4)
cp .env.example .env
# edite o .env:  SIM=0 · REQUIRE_CAMERA_CALIBRATION=1
#   SERIAL_PORT=<a porta do passo 5>
# (notas: MAP= no .env não é lido — mapa padrão hardcoded em config.DEFAULT_MAP;
#  CAMERA_INDEX e CAMERA_FRAME_WIDTH/HEIGHT também não são lidos do .env —
#  fixados no config.py em 0 e 1280×720; a captura força a resolução do JSON
#  de calibração)
```

**Regra da porta serial:** só um programa pode usar a UART por vez.
`pio device monitor`, `bench_setpoint.py` e o backend disputam a mesma porta —
sempre feche um antes de abrir o outro (erro típico: `Device or resource busy`).

---

## FASE 1 — Check completo: tudo conectado e conversando (robô suspenso, nada anda)

### 1.1 Fiação (fonte desligada)

Pinos (config.h, conferidos 2026-07-06): ESQ 27/26/25 (canal B) · DIR 12/14/13 (canal A) · Garfo 18/19/5 · ENC-E 23/15 (refiado, era 34/35) · ENC-D 32/33 · I2C 21/22.

- [ ] Sem pull-up externo nos encoders — 23/15 e 32/33 têm pull-up interno (`INPUT_PULLUP`); 34/35 ficaram livres (se reutilizados, aí sim exigem 10 kΩ → 3V3)
- [ ] Nenhum pull-up no GPIO 12 (strapping — ESP32 não sobe/não grava se HIGH no boot)
- [ ] Jumpers ENA/ENB removidos dos dois L298n
- [ ] GND comum em estrela (fonte, 2× L298n, ESP32, Pi, MPU)
- [ ] Multímetro na saída dos encoders NXT: > 3,3 V → level shifter/divisor
- [ ] Fim-de-curso: nada ligado (desabilitado com -1 — esperado)
- [ ] Recomendado (quando possível): migrar a alimentação dos encoders dos GPIOs
      2/4 para os pinos 3V3/GND reais da placa e setar `PIN_ENC_POWER_VCC/GND
      = -1` no config.h — GPIO fornece pouca corrente e o GPIO 2 é strapping de
      boot (atrapalha a gravação; ver troubleshooting do 1.2)

### 1.2 Firmware: compilar, gravar, ver sensores (no Pi, ESP32 no USB do Pi)

```bash
cd ~/Empilhadeira/src/firmware
source ../.venv/bin/activate          # pio foi instalado no venv (Fase 0)
pio run                              # 1ª vez demora (baixa toolchain) — deve terminar em SUCCESS
pio run -t upload                     # se travar em "Connecting...", segurar o botão BOOT
pio device monitor -b 115200
```

**Esperado:** JSON @ ~20 Hz com `|az|≈9.8–11` no MPU (no nosso chassi o z
aponta para baixo → `az` negativo, ~-11, comportamento esperado).

Checks de sensor (na mão, sem motor):
1. Girar cada roda para frente → `enc.esq`/`enc.dir` positivos.
   Negativo → inverter o `ENC_*_INV` em `config.h`, regravar (validado
   2026-07-06: `ENC_ESQ_INV=true`, `ENC_DIR_INV=true`).
   Esquerdo sempre zero → fiação do 1.1.
2. 1 volta exata → ~1440 contagens (x4; senão ajustar `ENCODER_PPR` nos dois configs).
3. **Isolamento entre encoders:** girar só uma roda → o `enc` da outra permanece
   em 0 (contar junto = cross-talk/fio trocado entre encoders).
4. **Simetria esq/dir:** empurrar o robô ~1 m em linha reta no chão → as duas
   colunas positivas e parecidas (±5%). Diferença sistemática = raio/PPR
   desigual → vai aparecer como curva suave no 2.1; anotar para o 3.1.
5. **Cadeia de yaw (encoders × gyro):** girar o robô no lugar, à mão,
   anti-horário (visto de cima) → `enc.esq` negativo, `enc.dir` positivo, e
   `gz` com sinal consistente durante o giro — anotar o sinal do gz (com o
   MPU de z para baixo, espera-se `gz` negativo no anti-horário). Valida a
   coerência encoder↔gyro antes do EKF, sem backend.
6. Inclinar o chassi → `ax/ay/az` mudam; deitar de lado → |g|≈10–11 migra de
   eixo (cada eixo vivo).

Erros: lixo no monitor = baudrate; nada = TX/RX invertidos ou cabo só-carga.
Gravação falhando (visto 2026-07-06: `Serial data stream stopped` /
`chip stopped responding`), na ordem: (a) repetir segurando o botão BOOT no
"Connecting..."; (b) desconectar o fio do GPIO 2 (VCC dos encoders —
strapping de boot) e regravar; (c) desligar a fonte 12 V/L298n durante a
gravação (GPIO 12 no IN do driver + ruído na USB); (d) `upload_speed = 115200`
no platformio.ini; (e) trocar o cabo USB / plugar direto no Pi.

Feche o `pio device monitor` (Ctrl-C) antes do próximo passo — a porta é uma só.

#### Resultados — modo display (robô ~fixo, sem motor), 2026-07-06

Caracterização do stream cru (`enc`/`mpu`) em 4 poses. Todas as convenções
de sinal do firmware/Pi foram confirmadas — nenhum ajuste de sinal foi
necessário; valida os fixes de giro de `a4bffcf`.

- **Repouso, chassi nivelado (Z para baixo):** `az ≈ -10.7` domina (faixa
  -9.5…-12.2 com ruído/vibração), `ax`/`ay ≈ 0`. `|g| ≈ 10.7` — ~9% acima de
  9.81. Como roll/pitch e a auto-orientação usam razões de eixos (`atan2`), essa
  escala alta é cosmética, não afeta heading nem tilt; fica anotada mas não
  recalibrada (uma pose limpa só não fecha calibração de 6 pontos).
- **Bias de taxa-zero do giroscópio (parado):** `gz ≈ 0` (±0.5 °/s) → bias de
  yaw desprezível, o `GyroCalibrator` o absorve. `gx ≈ -2.7`, `gy ≈ -1.0`
  °/s têm bias fixo, mas só entram no Kalman de roll/pitch (corrigido pelo
  acelerômetro, sem drift acumulado). Ver nota de melhoria abaixo.
- **Giro no lugar horário (visto de cima):** `enc.esq` positivo, `enc.dir`
  negativo, `gz` positivo (~+45…+64 °/s no pico).
- **Giro no lugar anti-horário:** `enc.esq` negativo, `enc.dir` positivo, `gz`
  negativo (~-50…-65 °/s). Bate com o check 5 do 1.2 (`gz` negativo no
  anti-horário) e com a convenção do EKF: `up = -Z` ⇒ `yaw = -gz`, logo
  anti-horário ⇒ `yaw` positivo = θ crescente. Confere.
- **Deitado de lado para a direita:** a gravidade migra para o eixo −Y
  (`ay ≈ -9` domina). Cada eixo "vivo" conforme o check 6 do 1.2. Confere.
- **Tombado para trás:** a gravidade migra para o eixo +X (`ax ≈ +9…+10.7`
  domina, `az → ~-2`). Confere.

Falhas do MPU observadas durante o teste (duas assinaturas distintas no
stream, úteis para diagnóstico futuro):
- `mpu` tudo-zero com `temp_c` = 36.53 (bursts durante os giros): o sensor
  entrou em sleep (I2C respondeu 14 bytes zerados; `temp = 0/340 + 36.53`).
  `readMpu` retorna false e o firmware auto-recupera re-enviando `mpuWake()`
  após ~1 s (20 leituras mortas @20 Hz).
- `mpu` tudo-zero com `temp_c` = 0 + `[E][Wire.cpp:499] requestFrom():
  i2cWriteReadNonStop returned Error 263` (no fim, após o tombo): o barramento
  I2C caiu (0 bytes; struct `Sensors` fica no default, `temp_c=0`). Recupera
  igual, mas é sintoma de contato/EMI — reassentar o MPU e afastar do L298n.
  Se persistir, considerar `Wire.setTimeout()`/reinício do barramento.

Melhoria pendente (não bloqueante): o Kalman (`pi/app/control/kalman.py`)
alimenta `u = [gx, gy]` crus; com bias ~-2.7/-1.0 °/s o acelerômetro corrige em
regime, mas seria mais limpo remover o bias por eixo (o `GyroCalibrator` já mede
`g_mean` parado — expor `gx/gy` bias). Requer teste próprio; deixado como TODO.

### 1.3 Motores em bancada (rodas no ar — fonte 12 V ligada)

```bash
cd ~/Empilhadeira/src && source .venv/bin/activate
python3 scripts/bench_setpoint.py                               # 2 rad/s frente, 5 s
python3 scripts/bench_setpoint.py --garfo subir --seconds 2     # garfo
```

(`--port /dev/ttyACM0` se for a porta anotada na Fase 0.)

1. **Um lado por vez primeiro** (constatado em 2026-07-06 — o teste conjunto
   não detecta canais trocados): `--w-esq 2 --w-dir 0` → só a roda esquerda
   gira, para frente; depois `--w-esq 0 --w-dir 2` → só a direita.
   Roda do lado errado girar = canais do L298n trocados → remapear
   `PIN_MOTOR_*` no `config.h` (já mapeado; regressão só se refizerem fios).
   Girar para trás = ajustar o `MOTOR_*_INV` daquele canal.
2. Juntas: as duas para frente e `enc.*` impresso ≈ +2.0 rad/s, subindo em
   degraus de ~0.44 (resolução x4 a 100 Hz) — fecha o ciclo
   comando→motor→encoder. Sintoma de canais cruzados: uma roda satura e a
   outra morre, alternando o lado entre execuções → voltar ao item 1.
3. `--garfo subir` sobe (senão `FORK_INV=true`). Soltar antes do fim do curso mecânico.
4. **Watchdog:** Ctrl-C com rodas girando → param em menos de 200 ms. Se
   reprovar, não avance.

### 1.4 Câmera no Pi (via SSH)

```bash
cd ~/Empilhadeira/src/pi && python3 teste_cam.py
```

Via SSH ele detecta que não há display e entra em modo headless sozinho
(só imprime no terminal; `HEADLESS=1` força, se precisar).

**Esperado:** `[OK] Detector criado com calibração` + `Câmera aberta (índice 0, 1280x720)`
+ detecções com id/z.

**Antes de tudo — câmera inclinada (montagem no topo do trilho do garfo):**
a câmera olha para baixo e o z do AprilTag sai na hipotenusa, não na
horizontal (erro que cresce de perto: +66% a 15 cm com 20 cm de desnível).
0. Medir e configurar o tilt (`CAMERA_TILT_DEG` no config, positivo = para
   baixo): tag centralizada na imagem → tilt = atan(Δh/d), onde Δh = desnível
   lente↔centro da tag e d = distância horizontal. Medições: 1ª montagem da
   câmera nova (2026-07-07): lente a 27,0 cm do chão, centro da tag a 15,3 cm,
   d = 27,9 cm → Δh = 11,7 → tilt = 22,7° (câmera antiga: 28,4°, lente a
   29,5 cm); remontagem (2ª vez): equipe mediu 30° →
   `CAMERA_TILT_DEG=30.0` no config. Depois de setar o tilt,
   recalibrar o `CAMERA_TO_FORK_OFFSET_CM` (offset medido sem compensação
   absorve o erro da hipotenusa). Atenção ao sinal do offset z: câmera atrás
   da ponta do garfo → offset z negativo (o código soma; o valor reportado deve
   diminuir até a referência do garfo).
0b. **Janela de visibilidade** (o motivo do tilt existir): aproximar a tag
   devagar de 1 m até 10 cm lendo o teste_cam → anotar em que faixa a
   detecção é segura; a faixa deve cobrir [15 cm, distância máxima do
   corredor]. Se perder a tag antes dos 15 cm, aumentar o tilt (e remedir).

Validações com fita métrica (com o tilt já configurado):
1. Tag a 30,0 cm horizontais → z entre 28,5–31,5 cm. Fora disso → tilt/offset
   errados, resolução de captura ≠ calibração, ou `tag_size` errado. Repetir a
   15 cm — é onde o erro de tilt apareceria (~+60% se descompensado).
2. Tag a 15 cm (standoff da navegação) → ainda detecta.
3. Anotar a distância máxima de detecção (< ~1,5 m compromete tags distantes).
4. Tamanho da tag = 4 cm (0,04 m), consistente nos três lugares:
   `config.APRILTAG_SIZE_CM = 4.0`, `tag_size_m: 0.04` nos mapas e o default de
   `vision/detector.py`. Conferir com paquímetro: se a tag impressa não for
   4 cm, o `z` sai proporcionalmente errado — reimprimir a 4 cm, ou atualizar os
   três ao valor real antes do 3.2.
5. **Sinal do x_cm** (convenção do projeto = a do simulador): tag deslocada à
   esquerda do centro da imagem → `x_cm` positivo (o `pose.py` nega o
   x do frame OpenCV desde 2026-07-06; se vier negativo, a negação se perdeu —
   sem ela a autonomia vira para longe da tag).
6. **Sinal do pitch_deg**: girar a tag no eixo vertical (borda esquerda para
   perto da câmera, depois a direita) → o `pitch_deg` deve trocar de sinal de
   forma consistente. Anotar a convenção observada e conferir contra o FACE no
   3.2 — a extração de Euler da câmera real ainda não foi validada contra o
   simulador.

### 1.5 Backend no Pi + frontend (conforme a topologia da Fase 0)

`.env` no Pi (base no `.env.example`):

```bash
SIM=0
REQUIRE_CAMERA_CALIBRATION=1
# MAP= no .env não é lido — mapa padrão: config.DEFAULT_MAP = corredor_6tags_80x160
# CAMERA_INDEX e CAMERA_FRAME_WIDTH/HEIGHT também não são lidos do .env —
# fixados no config.py (0 e 1280×720; a captura força o image_size da calibração)
SERIAL_PORT=/dev/ttyUSB0        # a porta anotada na Fase 0
```

**No Pi (SSH) — backend:**
```bash
cd ~/Empilhadeira/src && ./scripts/run_pi.sh
```

| Log esperado (ordem) | Se não aparecer |
|---|---|
| `Modo REAL (hardware)` | `.env` não carregou ou SIM≠0 |
| `Serial loop (REAL) iniciado` | porta errada/ocupada (fechou o monitor? bench?), ou grupo dialout sem relogar |
| `Detector criado com calibração` | JSON de calibração quebrado → refazer 1.4 |

**Frontend — modo DEV (servido pelo Mac):**
```bash
# no .env do Mac:  VITE_PI_WS_URL=ws://<IP_DO_PI>:8000/ws
cd src/frontend && npm run dev        # já expõe na rede (host: true), porta 5173
```
Abrir no navegador do Mac ou do celular: `http://<IP_DO_MAC>:5173`.
Mudou o `VITE_PI_WS_URL`? Reiniciar o `npm run dev` (a env é lida na partida).

**Frontend — modo OPERAÇÃO (servido pelo backend do Pi, sem Node no Pi):**
```bash
# No Mac: buildar e copiar os estáticos
cd src/frontend && npm run build
rsync -av dist/ pi@<IP_DO_PI>:~/Empilhadeira/src/frontend/dist/
# No Pi: reiniciar o backend — log deve mostrar "Frontend estático montado"
```
Celular abre `http://<IP_DO_PI>:8000/` — uma porta só; sem `VITE_PI_WS_URL`
o frontend conecta em `ws://<host da página>:8000/ws`, que já é o Pi.

**Validação (igual nos dois modos):** telemetria ~20 Hz na tela; girar roda na
mão move `rodas`; inclinar move `imu`; tag na frente da câmera →
`visao.detectado=true`.
Não conecta → conferir se estão na mesma rede Wi-Fi, os IPs (`hostname -I` no
Pi, `ipconfig getifaddr en0` no Mac) e a porta 8000
(`curl http://<IP_DO_PI>:8000/maps/current` de outra máquina).

### Portão 1
Frames 20 Hz · encoders positivos para frente (~1440/volta) · motores no lado e
sentido certos (um por vez) · watchdog < 200 ms · câmera com z correto na fita
e sinais de x_cm/pitch validados · telemetria no celular.

---

## FASE 2 — Só modo MANUAL (robô no chão, área livre, mão no PARADO)

**Não clicar em AUTOMATICO nesta fase.**

### 2.0 Ritual de boot (gyro)
Subir o backend e deixar o robô imóvel por ~3 s. O GyroCalibrator usa a gravidade
para detectar o eixo vertical, o sinal do yaw e o bias (a posição do MPU no chassi
não importa, desde que um eixo fique vertical; > 10° de inclinação gera aviso no log).
Robô em movimento no boot = calibração adiada até a primeira parada.
Chão firme e ninguém tocando no robô nesses 3 s — os pneus macios deixam o
chassi balançando (visto no monitor em 2026-07-06: accel/gyro ondulando a ~1 Hz
com o robô parado); calibrar com o chassi balançando gera bias ruim e heading
derivando.

### 2.1 Joystick e botões de comando exato

> Para os testes de retidão e giro use o painel "Comando exato" (D-pad
> abaixo do joystick, adicionado 2026-07-06): os botões enviam vetores puros
> (Frente = ω exatamente 0; Gira = v exatamente 0) com heartbeat automático —
> eliminam a variação da mão do operador. Escala 30/60/100% da velocidade
> máxima. O joystick analógico continua valendo para dirigibilidade geral.

| Teste | Esperado | Se falhar |
|---|---|---|
| Frente devagar | Anda reto | Vira no lugar = inversão de um lado (voltar ao 1.3); curva suave = PPR/raio desigual — anotar para a Fase 3 |
| Ré | Reto para trás | idem |
| Joystick à direita | Gira à direita (e à esquerda para a esquerda) | Invertido = regressão do sinal do ω em `joystick_to_twist` (corrigido 2026-07-06: ω = -x; convenção ω positivo = anti-horário) |
| Giro no lugar | Gira sem transladar | cinemática/wheelbase — anotar |
| Giro anti-horário | Heading da telemetria aumenta (θ anti-horário positivo) | sinal do gyro/odometria — conferir GyroCalibrator e convenção antes do EKF (3.4) |
| Parado | Heading da telemetria estável | gyro não calibrou (2.0) |
| Talo baixo (~20%) | Pode demorar ~1–2 s para partir ou nem partir | Comportamento esperado: duty baixo não vence o atrito estático; o integral do PID acumula devagar. Anotar o menor talo que anda → informa a sintonia do 3.1 (subir Ki ajuda a partida) |

### 2.2 Garfo com carga
Vazio, depois com o pallet real. `FORK_DUTY` já subiu 180→220 na bancada
(2026-07-06/07) para levantar com carga; se ainda não subir, aumentar mais e regravar.
Sempre soltar antes do limite mecânico (não há fim-de-curso). Worm gear segura parado.

### 2.3 Os dois watchdogs (com o robô andando)
1. Desplugar USB do ESP32 andando → para em menos de 200 ms.
2. Desligar Wi-Fi do celular andando → para em menos de ~400 ms (`COMMAND_WATCHDOG_MS`).

### 2.4 Sanidade de odometria e visão (dirigindo manual)
Use os botões de Comando exato (2.1) — reta e giro puros deixam o teste
reproduzível:
1. 1 m reto medido com fita → pose avança ~1 m (erro grande = `WHEEL_RADIUS`/PPR).
2. 360° no lugar → heading volta ~ao mesmo valor (erro grande = `WHEEL_BASE` ou gyro).
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

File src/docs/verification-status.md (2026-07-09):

# Status de Verificação — Simulação e Testes

Última contagem: 2026-07-08 (achados das sessões de simulação, antes em `ACHADOS_SIM.md` e `ACHADOS_SIM_v2.md`).

---

O sistema está funcional e validado em simulação. A lógica de controle, missão,
navegação e telemetria roda identicamente em `SIM=1` e `SIM=0` — só mudam os encaixes
de hardware (câmera e serial).
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

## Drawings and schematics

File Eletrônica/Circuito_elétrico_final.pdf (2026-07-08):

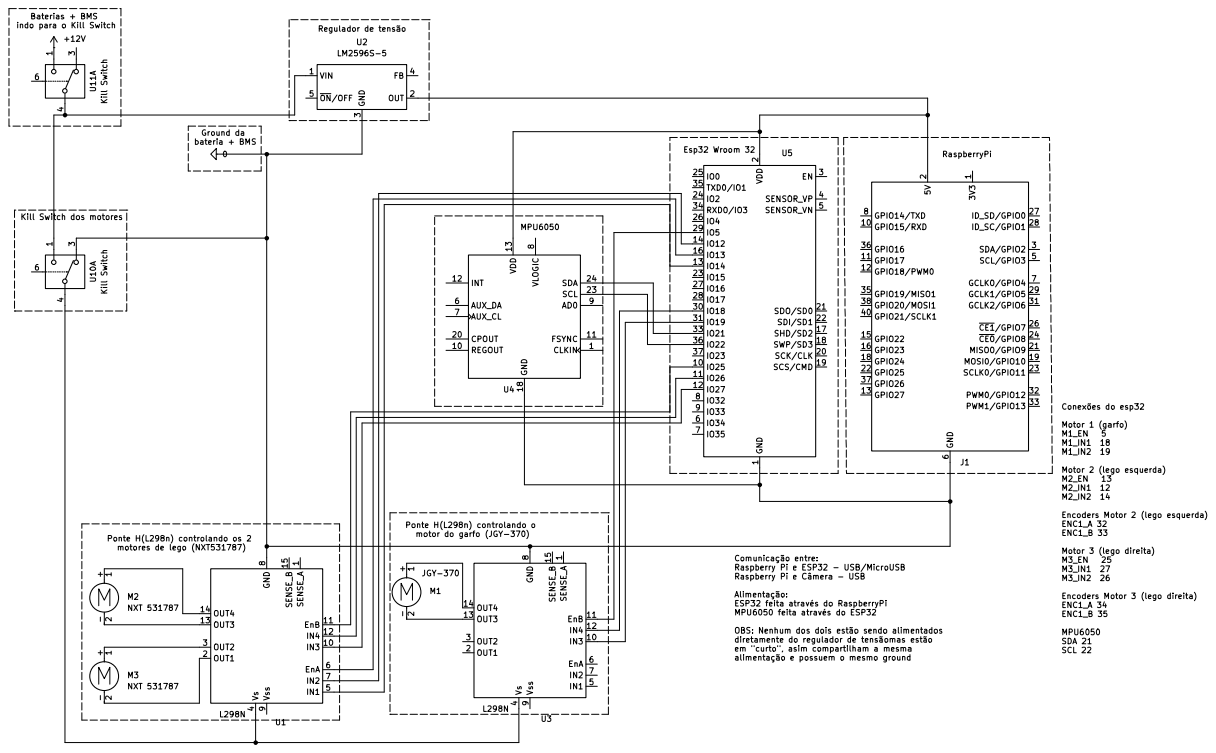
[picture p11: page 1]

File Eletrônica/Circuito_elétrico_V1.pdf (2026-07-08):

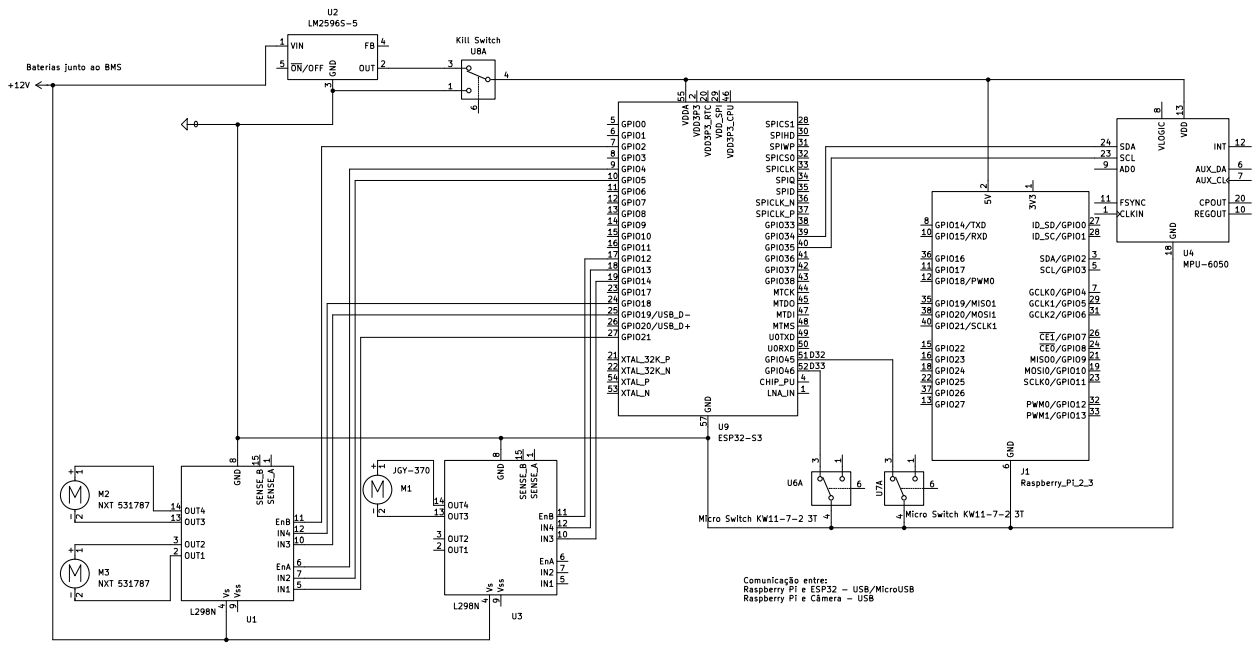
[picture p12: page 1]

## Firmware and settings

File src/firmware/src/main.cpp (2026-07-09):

/**
 * main.cpp — Loop principal do ESP32.
 *
 * Duas cadencias: PID ~100 Hz (encoders + motores + garfo) e serial ~20 Hz
 * (MPU-6050 + telemetria ao Pi). Setpoints chegam via UART sem bloqueio;
 * watchdog para em SETPOINT_TIMEOUT_MS se o Pi parar de enviar.
 */
#include <Arduino.h>
#include <Wire.h>

#include "config.h"
#include "encoders.h"
#include "motors.h"
#include "pid.h"
#include "protocol.h"

// --- MPU-6050 ---
// Registradores relevantes do MPU-6050 (datasheet RM-MPU-6000A).
static constexpr uint8_t REG_PWR_MGMT_1    = 0x6B;
static constexpr uint8_t REG_ACCEL_XOUT_H  = 0x3B;

// +-2g (16384 LSB/g), +-250 deg/s (131 LSB/(deg/s)), temp: raw/340 + 36.53
static constexpr float ACCEL_SCALE = 9.81f / 16384.0f;
static constexpr float GYRO_SCALE  = 1.0f / 131.0f;
static constexpr float TEMP_SCALE  = 1.0f / 340.0f;
static constexpr float TEMP_OFFSET = 36.53f;

// AX,AY,AZ (6) + TEMP (2) + GX,GY,GZ (6) = 14 bytes
static constexpr uint8_t MPU_READ_LEN = 14;

static Pid pidEsq(PID_KP_ESQ, PID_KI_ESQ, PID_KD_ESQ);
static Pid pidDir(PID_KP_DIR, PID_KI_DIR, PID_KD_DIR);

static Setpoint lastSetpoint;
static unsigned long lastSetpointMs = 0;
static bool setpointValid = false;

static float measuredEsq = 0.0f;
static float measuredDir = 0.0f;

static unsigned long lastPidMs    = 0;
static unsigned long lastSerialMs = 0;

static char rxBuffer[256];
static SetpointFrameDecoder decoder(rxBuffer, sizeof(rxBuffer));
static char txBuffer[512];

/**
 * Le um valor raw de 16 bits (big-endian) do barramento I2C.
 * O MPU-6050 transmite MSB primeiro.
 */
static inline int16_t readRaw16() {
  const uint8_t hi = static_cast<uint8_t>(Wire.read());
  const uint8_t lo = static_cast<uint8_t>(Wire.read());
  return static_cast<int16_t>((hi << 8) | lo);
}

/**
 * Acorda o MPU-6050: limpa o bit SLEEP no registrador PWR_MGMT_1.
 * Chamado no setup() e re-chamado pelo loop() se o sensor aparentar morto
 * (auto-recuperacao: um write de wake que falha por mau contato no boot
 * deixaria o MPU dormindo e reportando zeros para sempre).
 */
static void mpuWake() {
  Wire.beginTransmission(MPU6050_ADDR);
  Wire.write(REG_PWR_MGMT_1);
  Wire.write(0x00);
  Wire.endTransmission();
}

/**
 * Le todos os sensores do MPU-6050 (burst read de 14 bytes a partir de 0x3B)
 * e preenche os campos correspondentes na struct Sensors.
 *
 * Ordem dos registradores no burst:
 *   ACCEL_XOUT_H/L, ACCEL_YOUT_H/L, ACCEL_ZOUT_H/L,
 *   TEMP_OUT_H/L,
 *   GYRO_XOUT_H/L, GYRO_YOUT_H/L, GYRO_ZOUT_H/L
 *
 * @return true se a leitura veio completa e com dados vivos; false em duas
 *         falhas observadas na bancada (2026-07-06, modo display), com
 *         assinaturas DISTINTAS no stream:
 *           - Barramento I2C caiu: requestFrom nao entrega 14 bytes
 *             ([E][Wire.cpp] Error 263). Retorna false ANTES de tocar os
 *             campos → frame sai com o default da struct, inclusive temp_c=0.
 *           - Sensor dormindo: I2C entrega 14 bytes TODOS zero (fisicamente
 *             impossivel com o acelerometro ligado, que sempre mostra
 *             gravidade + ruido). Os campos ja foram escritos como 0 e
 *             temp_c = 0/340 + 36.53 = 36.53 → essa e a assinatura no stream.
 *         Em ambos o loop() auto-recupera via mpuWake() (ver abaixo).
 */
static bool readMpu(Sensors& s) {
  Wire.beginTransmission(MPU6050_ADDR);
  Wire.write(REG_ACCEL_XOUT_H);
  Wire.endTransmission(false);
  Wire.requestFrom(MPU6050_ADDR, MPU_READ_LEN, static_cast<uint8_t>(true));

  if (Wire.available() < MPU_READ_LEN) {
    return false;
  }

  const int16_t raw_ax   = readRaw16();
  const int16_t raw_ay   = readRaw16();
  const int16_t raw_az   = readRaw16();
  const int16_t raw_temp = readRaw16();
  const int16_t raw_gx   = readRaw16();
  const int16_t raw_gy   = readRaw16();
  const int16_t raw_gz   = readRaw16();

  s.ax = static_cast<float>(raw_ax) * ACCEL_SCALE;
  s.ay = static_cast<float>(raw_ay) * ACCEL_SCALE;
  s.az = static_cast<float>(raw_az) * ACCEL_SCALE;
  s.gx = static_cast<float>(raw_gx) * GYRO_SCALE;
  s.gy = static_cast<float>(raw_gy) * GYRO_SCALE;
  s.gz = static_cast<float>(raw_gz) * GYRO_SCALE;
  s.mpu_temp_c = static_cast<float>(raw_temp) * TEMP_SCALE + TEMP_OFFSET;

  const bool all_zero = raw_ax == 0 && raw_ay == 0 && raw_az == 0 &&
                        raw_gx == 0 && raw_gy == 0 && raw_gz == 0 &&
                        raw_temp == 0;
  return !all_zero;
}

// --- Setup ---

void setup() {
  Serial.begin(SERIAL_BAUDRATE);

  motorsBegin();
  encodersBegin();

  Wire.begin(PIN_I2C_SDA, PIN_I2C_SCL);

  // Acorda o MPU-6050 (+-2g, +-250 deg/s).
  mpuWake();

  // O datasheet do MPU-6050 (RM-MPU-6000A, secao 4.1) especifica que o
  // giroscopio precisa de ate 30 ms para estabilizar apos sair do modo SLEEP.
  // Aguardamos 50 ms por margem para garantir que a primeira leitura ja seja
  // valida. Sem esse delay, as primeiras amostras de gyro podem ser lixo.
  delay(50);

  const unsigned long now = millis();
  lastPidMs    = now;
  lastSerialMs = now;
}

// --- Loop principal ---

void loop() {
  const unsigned long now = millis();

  while (Serial.available() > 0) {
    Setpoint sp;
    if (decoder.push(static_cast<uint8_t>(Serial.read()), sp)) {
      lastSetpoint   = sp;
      lastSetpointMs = now;
      setpointValid  = true;
    }
  }

  // Watchdog: sem setpoint novo dentro do timeout -> estado seguro.
  if (setpointValid && SETPOINT_TIMEOUT_MS > 0 &&
      (now - lastSetpointMs) > SETPOINT_TIMEOUT_MS) {
    motorsStop();
    pidEsq.reset();
    pidDir.reset();
    setpointValid = false;
  }

  // Malha PID ~100 Hz
  const unsigned long pidIntervalMs = static_cast<unsigned long>(1000.0f / PID_HZ);
  if (now - lastPidMs >= pidIntervalMs) {
    const float dt_s = static_cast<float>(now - lastPidMs) / 1000.0f;
    lastPidMs = now;

    measuredEsq = encoderReadEsq(dt_s);
    measuredDir = encoderReadDir(dt_s);

    if (setpointValid) {
      // Setpoint ZERO = parada comandada INCONDICIONAL: nao passa pelo PID.
      // Com encoder morto (medido=0), o erro de um setpoint 0 seria 0 e o
      // integral acumulado na conducao seguraria duty maximo para sempre
      // (u = Ki*integral) — o robo ignoraria o PARADO. Bug visto na bancada
      // em 2026-07-06 (roda direita sem pull-up nao parava).
      if (lastSetpoint.w_esq == 0.0f) {
        pidEsq.reset();
        motorSetWheelEsq(0.0f);
      } else {
        pidEsq.setSetpoint(lastSetpoint.w_esq);
        motorSetWheelEsq(pidEsq.update(measuredEsq, dt_s));
      }

      if (lastSetpoint.w_dir == 0.0f) {
        pidDir.reset();
        motorSetWheelDir(0.0f);
      } else {
        pidDir.setSetpoint(lastSetpoint.w_dir);
        motorSetWheelDir(pidDir.update(measuredDir, dt_s));
      }

      motorSetFork(lastSetpoint.garfo);
    }
  }

  // Serial ~20 Hz: telemetria ao Pi
  const unsigned long serialIntervalMs = static_cast<unsigned long>(1000.0f / SERIAL_HZ);
  if (now - lastSerialMs >= serialIntervalMs) {
    lastSerialMs = now;

    Sensors sensors;
    sensors.enc_esq = measuredEsq;
    sensors.enc_dir = measuredDir;

    // Auto-recuperacao do MPU: se ~1 s de leituras mortas (I2C falhou ou
    // sensor dormindo apos wake perdido no boot), re-envia o comando de wake.
    static uint8_t mpuDeadReads = 0;
    if (readMpu(sensors)) {
      mpuDeadReads = 0;
    } else if (++mpuDeadReads >= 20) {  // 20 ciclos @ 20 Hz = 1 s
      mpuWake();
      mpuDeadReads = 0;
    }

    // TODO(equipe): integrar BMS se a versao escolhida suportar leitura digital.
    // Caso contrario, has_bms permanece false e o campo "bms" sera null no JSON.
    sensors.has_bms = false;

    const size_t len = encodeSensors(sensors, txBuffer, sizeof(txBuffer));
    if (len > 0) {
      Serial.write(txBuffer, len);
    }
  }
}

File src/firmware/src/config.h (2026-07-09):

/**
 * config.h — Pinos, taxas e ganhos do firmware do ESP32.
 *
 * Mapa de GPIOs alinhado com Testes_eletronica.ino (placa real).
 * Ganhos PID: valores iniciais conservadores para Lego NXT 53787;
 * ajustar empiricamente com Ziegler-Nichols (ver README).
 */
#pragma once

#include <stdint.h>

// --- Calibracao pendente no robo real ---
// [F] = config.h (firmware).  [P] = app/config.py (Pi).
//
// Firmware (este arquivo):
//  1. [F] ENCODER_PPR .......... (atual 1440 = 360 ciclos x4 da quadratura)
//         COMO: gire a roda à mão EXATAMENTE 10 voltas completas e leia o total
//         de pulsos contados; PPR = pulsos / 10. Com a decodificação x4
//         (encoders.cpp) o esperado é ~14400 em 10 voltas. Atualizar aqui E o
//         EMU_ENCODER_PPR no config.py.
//
//  2. [F] MOTOR_ESQ_INV / MOTOR_DIR_INV ... (sentido dos motores)
//         COMO: enviar setpoint linear POSITIVO. As DUAS rodas devem girar para
//         FRENTE. Se uma girar ao contrário, inverter o *_INV dela.
//
//  3. [F] ENC_ESQ_INV / ENC_DIR_INV ....... (sentido dos encoders)
//         COMO: empurrar a roda para FRENTE; o omega reportado deve ser
//         POSITIVO. Se vier negativo, inverter o *_INV dela.
//
//  4. [F] FORK_INV ............. (sentido do garfo)
//         COMO: comando "subir" deve SUBIR o garfo. Se descer, trocar para true.
//
//  5. [F] FORK_DUTY ............ (atual 220, escala 0-255)
//         COMO: com a carga MÁXIMA prevista, achar o menor duty que ainda
//         levanta o garfo com folga. Subir se patinar; descer se for brusco.
//
//  6. [F] PID_K{P,I,D}_{ESQ,DIR} .. (atuais 20 / 5 / 1)
//         COMO: Ziegler-Nichols. Zerar Ki e Kd; subir Kp até oscilação
//         sustentada → Ku; medir o período dessa oscilação → Tu (s). Então
//         Kp=0.6*Ku, Ki=2*Kp/Tu, Kd=Kp*Tu/8. Repetir por roda.
//
//  7. [F] PIN_FORK_LIMIT_TOP / _BOTTOM ... (atuais -1 = sem chave)
//         COMO: quando as chaves de fim-de-curso forem montadas, definir os
//         GPIOs livres reais (lembrar que o GPIO 5 agora é o PWM do garfo).
//
// Lado Pi (app/config.py) — geometria/optica:
//  8. [P] WHEEL_BASE_L_CM ...... (atual 15.0 cm) — BITOLA: distância entre os
//         pontos de contato das DUAS rodas no chão. Paquímetro/régua, em cm.
//  9. [P] WHEEL_RADIUS_R_CM .... (atual 2.7 cm) — meça o DIÂMETRO externo da
//         roda (com o peso do robô sobre ela) e divida por 2, em cm.
// 10. [P] MAX_LINEAR_SPEED / MAX_ANGULAR_SPEED — v (cm/s) e ω (rad/s) MÁXIMOS
//         reais: cronometre o robô a duty máximo por distância/ângulo conhecidos.
// 11. [P] APRILTAG_SIZE_CM ..... (atual 4.0 cm) — meça o lado do quadrado PRETO
//         da tag impressa (sem a borda branca), em cm.
// 12. [P] CAMERA_TO_FORK_OFFSET_CM ... (atual 0.0, -14.2, -10.0) — (x, y, z) em cm do centro
//         óptico da câmera até o ponto de referência do garfo.
//         (Intrínsecos fx/fy/cx/cy da câmera: JÁ calibrados em
//          calibracao/camera_intrinsics.json.)

// --- Serial (UART Pi <-> ESP32) ---
constexpr unsigned long SERIAL_BAUDRATE = 115200;
constexpr float SERIAL_HZ = 20.0f;                 // taxa de troca de mensagens

// Timeout do setpoint: se nenhum setpoint novo chegar nesse intervalo, o ESP32
// entra em estado seguro (motores zerados, PID resetado).
// 200 ms = 4 mensagens perdidas a 20 Hz — margem suficiente para jitter da
// serial sem falsos positivos, mas rapido o bastante para parar o robo se
// o Pi realmente desconectar.
constexpr unsigned long SETPOINT_TIMEOUT_MS = 200;

// --- Malha de controle ---
constexpr float PID_HZ = 100.0f;

// Ganhos PID por roda — valores iniciais para Lego NXT 53787 @ 12V via L298n.
//
// Logica dos valores:
//   Motor NXT 53787: ~117 RPM = ~12.25 rad/s no eixo de saida.
//   LEDC 8 bits: duty 0-255.
//   Para 1 rad/s de erro, queremos ~20 unidades de duty → Kp ≈ 20.
//   Ki baixo para correcao de regime sem overshoot: Ki ≈ 5.
//   Kd conservador para amortecer oscilacoes: Kd ≈ 1.
//
// Procedimento de ajuste (Ziegler-Nichols simplificado):
//   1. Zerar Ki e Kd.
//   2. Aumentar Kp ate o motor oscilar → esse Kp = Ku (ganho critico).
//   3. Medir o periodo da oscilacao → Tu.
//   4. Kp = 0.6*Ku, Ki = 2*Kp/Tu, Kd = Kp*Tu/8.
//   5. Ajustar empiricamente a partir dai.
constexpr float PID_KP_ESQ = 20.0f;
constexpr float PID_KI_ESQ = 5.0f;
constexpr float PID_KD_ESQ = 1.0f;
constexpr float PID_KP_DIR = 20.0f;
constexpr float PID_KI_DIR = 5.0f;
constexpr float PID_KD_DIR = 1.0f;

// Limite do termo integral (anti-windup por clamping).
// Com Ki=5 e MAX_DUTY=255, limitamos a integral a ~2x MAX_DUTY para que o
// termo integral sozinho nao sature o atuador indefinidamente.
constexpr float PID_INTEGRAL_LIMIT = 500.0f;
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

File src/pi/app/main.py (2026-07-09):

"""Ponto de entrada do backend do Pi.

SIM=1: mapa + mundo parametrizado + emulador + visão sintética.
SIM=0: serial real + câmera real.

    uvicorn app.main:create_app --factory --host 0.0.0.0 --port 8000
"""

from __future__ import annotations

import asyncio
import logging
from contextlib import asynccontextmanager
from pathlib import Path

from fastapi import FastAPI, WebSocket
from fastapi.middleware.cors import CORSMiddleware
from pydantic import BaseModel

from app import config
from app.state import SharedState
from app.world.map_schema import load_map
from app.world.world_model import WorldModel

logger = logging.getLogger(__name__)

_state: SharedState | None = None
_emulator = None
_world = None
_synthetic_vision = None
_fault_injector = None


class PoseResetRequest(BaseModel):
    x: float
    y: float
    theta: float


class FaultRequest(BaseModel):
    fault_type: str
    active: bool = True
    value: float | None = None
    value2: float | None = None


class MissionStartRequest(BaseModel):
    pick_id: str | None = None
    place_id: str | None = None


class DockEnableRequest(BaseModel):
    """Corpo opcional de POST /dock/enable."""
    mode: str | None = None       # "line_of_sight" (default real) | "tag_normal"
    standoff_m: float | None = None


def _resolve_map_path(map_name: str) -> Path:
    """Resolve o caminho de um mapa pelo nome."""
    maps_dir = config.MAPS_DIR
    path = maps_dir / f"{map_name}.json"
    if path.exists():
        return path
    raise FileNotFoundError(f"Mapa '{map_name}' não encontrado em {maps_dir}")


def _load_world_model(map_name: str) -> WorldModel:
    """Carrega o WorldModel de um mapa pelo nome."""
    path = _resolve_map_path(map_name)
    return WorldModel.from_file(path)


def _setup_sim_world(state: SharedState, world_model: WorldModel):
    """Configura o mundo simulado a partir do WorldModel.

    Armazena referências em ``state`` para hot-swap nas tasks asyncio.
    """
    global _world, _emulator, _synthetic_vision, _fault_injector

    from app.sim.fault_injector import FaultInjector
    from app.sim.firmware_emulator import FirmwareEmulator
    from app.sim.synthetic_vision import SyntheticVision
    from app.sim.world import SimWorld

    _world = SimWorld(world_model=world_model, robot_model=state.robot_model)
    _emulator = FirmwareEmulator(world=_world)
    _synthetic_vision = SyntheticVision()
    _fault_injector = FaultInjector()
    _fault_injector.bind(_emulator, _synthetic_vision, _world)

    state.sim_emulator = _emulator
    state.sim_world = _world
    state.sim_vision = _synthetic_vision
    state.load_world(world_model)


@asynccontextmanager
async def lifespan(app: FastAPI):
    """Gerencia ciclo de vida: inicia tarefas no startup, cancela no shutdown."""
    global _state

    logging.basicConfig(
        level=logging.INFO,
        format="%(asctime)s [%(name)s] %(levelname)s: %(message)s",
    )

    _state = SharedState()
    tasks: list[asyncio.Task] = []

    if config.SIM:
        logger.info("Modo SIMULAÇÃO (SIM=1)")

        try:
            world_model = _load_world_model(config.DEFAULT_MAP)
            _setup_sim_world(_state, world_model)
            logger.info("Mapa carregado: %s", config.DEFAULT_MAP)
        except FileNotFoundError as e:
            logger.warning("Mapa padrão não encontrado: %s — usando fallback", e)
            from app.sim.fault_injector import FaultInjector
            from app.sim.firmware_emulator import FirmwareEmulator
            from app.sim.synthetic_vision import SyntheticVision
            from app.sim.world import SimWorld
            global _world, _emulator, _synthetic_vision, _fault_injector
            _world = SimWorld()
            _emulator = FirmwareEmulator(world=_world)
            _synthetic_vision = SyntheticVision()
            _fault_injector = FaultInjector()
            _fault_injector.bind(_emulator, _synthetic_vision, _world)
            _state.sim_emulator = _emulator
            _state.sim_world = _world
            _state.sim_vision = _synthetic_vision

        from app.tasks.serial_loop import serial_loop_sim
        from app.tasks.vision_loop import SimVisionSource, vision_loop

        vision_source = SimVisionSource(_state)
        tasks.append(asyncio.create_task(serial_loop_sim(_state)))
        tasks.append(asyncio.create_task(vision_loop(_state, vision_source)))
    else:
        logger.info("Modo REAL (hardware)")
        from app.tasks.serial_loop import serial_loop_real
        from app.tasks.vision_loop import RealVisionSource, vision_loop

        try:
            world_model = _load_world_model(config.DEFAULT_MAP)
            _state.load_world(world_model)
            logger.info("Mapa carregado (modo real): %s", config.DEFAULT_MAP)
        except FileNotFoundError:
            logger.warning("Mapa não encontrado para modo real — continuando sem mapa")

        try:
            vision_source = RealVisionSource()
            tasks.append(asyncio.create_task(vision_loop(_state, vision_source)))
        except Exception as e:
            logger.error("Visão real indisponível — seguindo sem visão: %s", e)

        try:
            tasks.append(asyncio.create_task(serial_loop_real(_state)))
        except Exception as e:
            logger.error("Serial real indisponível — seguindo sem serial: %s", e)

    from app.tasks.control_loop import control_loop

    tasks.append(asyncio.create_task(control_loop(_state)))

    logger.info("Tarefas asyncio iniciadas (%d)", len(tasks))

    yield

    for task in tasks:
        task.cancel()
    await asyncio.gather(*tasks, return_exceptions=True)
    logger.info("Tarefas asyncio finalizadas")


def create_app() -> FastAPI:
    app = FastAPI(title="Empilhadeira Pi", lifespan=lifespan)

    app.add_middleware(
        CORSMiddleware,
        allow_origins=["*"],
        allow_methods=["*"],
        allow_headers=["*"],
    )

    @app.websocket("/ws")
    async def ws_endpoint(websocket: WebSocket):
        from app.tasks.websocket_handler import websocket_endpoint

        if _state is None:
            await websocket.close()
            return
        await websocket_endpoint(websocket, _state)

    if config.SIM:
        _register_sim_routes(app)

    _register_mission_routes(app)
    _register_dock_routes(app)
    _register_world_state_route(app)
    _register_map_routes(app)
    _mount_frontend(app)

    return app
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

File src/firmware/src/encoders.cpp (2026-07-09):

/**
 * encoders.cpp — Leitura dos encoders de quadratura por interrupcao (ISR).
 *
 * Os motores Lego NXT (53787) possuem encoders de quadratura integrados com
 * duas fases (A e B). Estrategia de leitura — decodificacao COMPLETA (x4):
 *
 *   1. Attach de interrupcao em CHANGE nas DUAS fases (A e B) de cada encoder.
 *   2. A ISR le o estado atual (A<<1)|B e consulta uma tabela de transicao
 *      (estado anterior -> estado atual) que devolve -1, 0 ou +1:
 *      - Sequencia 00->10->11->01->00 (A adianta B) -> sentido positivo.
 *      - Sequencia inversa -> sentido negativo.
 *      - Transicao invalida (pulo de 2 estados, ruido) -> 0 (ignorada).
 *   3. Um contador volatile acumula os incrementos entre chamadas de leitura.
 *   4. A funcao de leitura (encoderReadEsq/Dir) calcula a velocidade angular
 *      em rad/s: omega = (pulsos / ENCODER_PPR) * 2*PI / dt_s.
 *
 * A decodificacao x4 conta as 4 bordas de cada ciclo de quadratura: 4x mais
 * resolucao que a leitura antiga (RISING-only em A) e rejeicao natural de
 * ruido — bounce numa fase gera transicoes que se cancelam (+1/-1) em vez de
 * acumular. ENCODER_PPR (config.h) = 1440 ja reflete o x4.
 *
 * CONVENCAO DE SINAL preservada da leitura antiga (validada na bancada em
 * 2026-07-06): "A subindo com B em LOW" conta POSITIVO. Os flags ENC_*_INV
 * validados continuam valendo.
 *
 * O acesso ao contador e feito em secao critica (noInterrupts/interrupts)
 * para atomicidade na leitura + reset do acumulador.
 *
 * A cinematica diferencial assume rodas sem escorregamento; se patinar,
 * a odometria degrada — tratado no Pi, nao aqui.
 */
#include "encoders.h"

#include <Arduino.h>

#include "config.h"

// Contadores de pulso — acessados tanto pela ISR quanto pelo loop principal.
// `volatile` garante que o compilador nao otimiza leituras em registrador.
static volatile long pulses_esq = 0;
static volatile long pulses_dir = 0;

// Ultimo estado (A<<1)|B de cada encoder, para a tabela de transicao.
static volatile uint8_t state_esq = 0;
static volatile uint8_t state_dir = 0;

// Tabela de transicao de quadratura, indexada por (estado_anterior<<2)|estado_atual.
// Estados: (A<<1)|B. Sequencia positiva: 0->2->3->1->0 (A subindo com B LOW = +1,
// mesma convencao da leitura antiga). Transicoes invalidas valem 0.
// DRAM_ATTR: ISRs em IRAM nao podem depender de dados na flash (.rodata).
DRAM_ATTR static const int8_t QDEC_LUT[16] = {
    0, -1, +1, 0,   // de 00 para: 00, 01, 10, 11
    +1, 0,  0, -1,  // de 01 para: 00, 01, 10, 11
    -1, 0,  0, +1,  // de 10 para: 00, 01, 10, 11
    0, +1, -1, 0,   // de 11 para: 00, 01, 10, 11
};

/**
 * ISR compartilhada pelas fases A e B do encoder esquerdo (CHANGE em ambas).
 * IRAM_ATTR coloca a funcao na IRAM do ESP32 para execucao rapida em contexto
 * de interrupcao (requisito do framework Arduino-ESP32).
 */
static void IRAM_ATTR isrEncoderEsq() {
  const uint8_t s = (static_cast<uint8_t>(digitalRead(PIN_ENC_ESQ_A)) << 1) |
                    static_cast<uint8_t>(digitalRead(PIN_ENC_ESQ_B));
  pulses_esq += QDEC_LUT[(state_esq << 2) | s];
  state_esq = s;
}

/**
 * ISR compartilhada pelas fases A e B do encoder direito.
 */
static void IRAM_ATTR isrEncoderDir() {
  const uint8_t s = (static_cast<uint8_t>(digitalRead(PIN_ENC_DIR_A)) << 1) |
                    static_cast<uint8_t>(digitalRead(PIN_ENC_DIR_B));
  pulses_dir += QDEC_LUT[(state_dir << 2) | s];
  state_dir = s;
}

void encodersBegin() {
  // Alimentacao do encoder via GPIO (fiacao da equipe): GPIO como "VCC"/"GND".
  // Energizar ANTES de configurar entradas/interrupcoes, para as fases ja
  // nascerem dirigidas pelo encoder (evita contagem fantasma no boot).
  if (PIN_ENC_POWER_GND >= 0) {
    pinMode(PIN_ENC_POWER_GND, OUTPUT);
    digitalWrite(PIN_ENC_POWER_GND, LOW);   // faz papel de GND
  }
  if (PIN_ENC_POWER_VCC >= 0) {
    pinMode(PIN_ENC_POWER_VCC, OUTPUT);
    digitalWrite(PIN_ENC_POWER_VCC, HIGH);  // faz papel de 3,3 V
  }

  pinMode(PIN_ENC_ESQ_A, INPUT_PULLUP);
  pinMode(PIN_ENC_ESQ_B, INPUT_PULLUP);
  pinMode(PIN_ENC_DIR_A, INPUT_PULLUP);
  pinMode(PIN_ENC_DIR_B, INPUT_PULLUP);

  // Semear o estado inicial com a posicao real das fases ANTES de anexar as
  // interrupcoes — senao a primeira transicao seria comparada contra 00
  // arbitrario e poderia contar um pulso invalido.
  state_esq = (static_cast<uint8_t>(digitalRead(PIN_ENC_ESQ_A)) << 1) |
              static_cast<uint8_t>(digitalRead(PIN_ENC_ESQ_B));
  state_dir = (static_cast<uint8_t>(digitalRead(PIN_ENC_DIR_A)) << 1) |
              static_cast<uint8_t>(digitalRead(PIN_ENC_DIR_B));

  attachInterrupt(digitalPinToInterrupt(PIN_ENC_ESQ_A), isrEncoderEsq, CHANGE);
  attachInterrupt(digitalPinToInterrupt(PIN_ENC_ESQ_B), isrEncoderEsq, CHANGE);
  attachInterrupt(digitalPinToInterrupt(PIN_ENC_DIR_A), isrEncoderDir, CHANGE);
  attachInterrupt(digitalPinToInterrupt(PIN_ENC_DIR_B), isrEncoderDir, CHANGE);

  pulses_esq = 0;
  pulses_dir = 0;
}

float encoderReadEsq(float dt_s) {
  if (dt_s <= 0.0f || ENCODER_PPR == 0) {
    return 0.0f;
  }

  noInterrupts();
  const long captured = pulses_esq;
  pulses_esq = 0;
  interrupts();

  const float revolutions = static_cast<float>(captured) / static_cast<float>(ENCODER_PPR);
  const float omega = (revolutions * 2.0f * PI) / dt_s;
  return ENC_ESQ_INV ? -omega : omega;
}

float encoderReadDir(float dt_s) {
  if (dt_s <= 0.0f || ENCODER_PPR == 0) {
    return 0.0f;
  }

  noInterrupts();
  const long captured = pulses_dir;
  pulses_dir = 0;
  interrupts();

  const float revolutions = static_cast<float>(captured) / static_cast<float>(ENCODER_PPR);
  const float omega = (revolutions * 2.0f * PI) / dt_s;
  return ENC_DIR_INV ? -omega : omega;
}

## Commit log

2026-05-26 feat: scaffold do monorepo da empilhadeira robótica
    Estrutura de 3 camadas (pi/ Python, firmware/ ESP32 C++, frontend/ React+Vite)
    com os 4 contratos congelados (docs/serial-protocol.md) espelhados em Pydantic,
    ArduinoJson e TypeScript. Apenas stubs tipados com docstrings PT-BR e
    NotImplementedError/// TODO — sem lógica de domínio. Parâmetros da Seção 3 como
    placeholders TODO(equipe). Tooling: pyproject (ruff/black/pytest), platformio.ini,
    package.json, .gitignore, .env.example.
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2026-06-09 feat(firmware): implementa lógica completa do ESP32
    Implementação de todos os stubs do firmware:
    - PID por roda com anti-windup (clamping integral)
    - Leitura de encoders por ISR (quadratura, IRAM_ATTR)
    - Acionamento PWM (LEDC) → L298n para rodas e garfo
    - Loop dual: PID ~100Hz + serial ~20Hz com millis()
    - Leitura MPU-6050 via I2C (burst read, dados crus)
    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
2026-06-09 feat(firmware): configura pinos reais e constantes para produção
    config.h: todos os placeholders substituídos por valores reais:
    - GPIOs mapeados para ESP32 DevKit V1 (evita strapping/flash pins)
    - Rodas: L298n #1 (GPIO 16/17/4 + 18/19/13)
    - Garfo: L298n #2 (GPIO 25/26/27) com duty 180 (~70%)
    - Encoders: GPIO 32/33 + 14/23 (com pullup)
    - Fim-de-curso: GPIO 5 (topo) + 15 (base), NO + pullup
    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
2026-06-15 feat(sim): camada de simulação completa + correções pós-execução ao vivo
    Sobe o sistema completo em modo SIM=1 (emulador de firmware, visão sintética,
    mundo físico, injeção de falhas) com loop de controle, navegação, máquina de
    estados, Kalman e telemetria, mais o frontend (operador + /demo).
    Correções encontradas ao rodar o sistema de fato (não só a suíte):
    - fix(sim-api): modelos Pydantic movidos p/ nível de módulo — rotas /sim/* davam
    HTTP 422 (from __future__ import annotations + classe local => query param).
    - fix(deps): adiciona 'websockets' — uvicorn puro não servia /ws (HTTP 404).
    - fix(control): novo tasks/control_loop.py @20Hz desacopla a malha fechada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
    [config.py, firmware_emulator.py, main.py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]
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2026-06-23 Fixed uvicorn for UV, added logging and small changes on vision (maybe changed later again)
    [main.py]
2026-06-23 feat(world): adiciona modelo de mundo, schema de mapas e arenas JSON
    Introduz WorldModel, map_schema e mapas de arena para navegação baseada em grafo.
2026-06-23 feat(control): EKF, planejador de rotas, Stanley e executor de segmentos
    Substitui navegação pontual por planejamento em grafo com fusão EKF e controle Stanley.
2026-06-23 feat(mission): máquina de estados pick-and-place com integração sim
    Implementa fluxo de missão autônoma com testes unitários e de integração.
2026-06-23 feat(hardware): abstrações de hardware e transporte serial para sim-to-real
    Prepara camada de interfaces e serial_transport para deploy em hardware real.
2026-06-23 feat(pi): expande config, modelos Pydantic e variáveis de ambiente
    Adiciona parâmetros de navegação, missão e mapas com testes de conversão de unidades.
2026-06-23 feat(pi): integra loops, visão e API de missão/mapa no backend
    Conecta estado compartilhado, control/vision loops e rotas REST para sim e produção.
2026-06-23 feat(sim): simulação com mapas, missões e visão sintética aprimorada
    Atualiza emulador, mundo simulado e injetor de falhas para suportar navegação em grafo.
2026-06-23 feat(frontend): painéis de missão, mapa, segurança e exportação de debug
    Estende demo UI com seletor de mapas, telemetria de missão e alertas de segurança.
2026-06-23 docs: guias sim-to-real, hardware, navegação e status de verificação
    Substitui relatórios ad hoc por documentação estruturada de arquitetura e readiness.
2026-06-23 docs: atualiza READMEs e AGENTS.md para navegação em grafo e missões
    Alinha documentação de entrada com a arquitetura sim-to-real e novos fluxos de demo.
2026-06-23 chore(deps): adota toolchain uv e uvicorn[standard] do main
    Traz a infraestrutura de dependências/runtime do main para o ramo mesclado:
    - pyproject: uvicorn[standard] (inclui websockets/uvloop) no lugar de
    "uvicorn" + "websockets" explícito; restaura o bloco [build-system].
    - uv.lock: lockfile do uv adicionado (build reprodutível).
    Vem de main (camada de runtime/infra), não altera a lógica do prodTest.
2026-06-23 feat(frontend): adota hook WebSocket e envDir do main como contrato real
    Camada de comunicação Frontend <-> Pi é fonte da verdade do main:
    - useWebSocket.js: versão do main (reconnect backoff até 10 s em vez de 5 s,
    guarda mountedRef contra setState pós-unmount). Interface de retorno
    { telemetry, connected, sendCommand } é idêntica, então os componentes do
    prodTest continuam funcionando sem mudança.
    - vite.config.js: restaura envDir "../" (carrega VITE_PI_WS_URL da raiz do
    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
2026-06-23 feat(pi): adota valores de watchdog do main (contrato de segurança)
    config.py recebe os parâmetros de watchdog do main como fonte da verdade:
    - COMMAND_WATCHDOG_MS: 500 -> 400 ms (valor de contrato do main; mantém o
    NOME usado pelo state_machine do prodTest para não quebrar o import).
    - SERIAL_LOST_FRAMES = 5: ciclos sem sensor que disparam PARADO (~250 ms@20Hz).
    Mantém CONTROL_HZ e os demais parâmetros de cinemática/navegação do prodTest.
2026-06-23 perf(vision): leitura de câmera real via asyncio.to_thread (infra do main)
    Aplica a melhoria de infra do main ao loop de visão do prodTest: a leitura
    OpenCV bloqueia o event loop, então para a fonte de câmera REAL a chamada
    source.get_vision() roda em asyncio.to_thread. SIM permanece síncrono
    (visão sintética é barata e evita corrida com o estado do mundo).
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2026-06-23 fix(frontend): honra VITE_PI_WS_URL como alvo do WebSocket (contrato do main)
    A merge trouxe envDir "../" e VITE_PI_WS_URL do main, mas App.jsx/DemoPage.jsx
    (UI do prodTest) montavam a URL só a partir de window.location, deixando a env
    sem consumidor. Agora a URL é import.meta.env.VITE_PI_WS_URL com fallback para
    mesmo-host. Permite apontar o frontend ao IP do Pi (ex.: ws://192.168.0.10:8000/ws),
    que é o contrato de comunicação real definido no main.
2026-06-23 fix(pi): liga watchdog serial (SERIAL_LOST_FRAMES) no serial_loop_real
    A merge trouxe SERIAL_LOST_FRAMES=5 do main, mas nenhum consumidor — config morta.
    Agora serial_loop_real conta ciclos consecutivos sem sensores e, ao atingir
    SERIAL_LOST_FRAMES (~250 ms @20 Hz), força PARADO via state_machine.force_stop
    (reason="serial_loss"). Defesa em profundidade sobre o SETPOINT_TIMEOUT_MS=200
    do firmware, que já zera os motores localmente se o Pi parar de enviar setpoint.
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2026-06-23 fix(frontend): torna useWebSocket seguro a StrictMode/navegação (fim do flapping)
    O hook reconectava com base num único mountedRef, então o onclose de um socket
    abortado (duplo-mount do StrictMode em dev, ou socket substituído) disparava
    depois que o remount já tinha reposto mountedRef=true e agendava reconexões
    espúrias em cima do socket vivo → sockets duplicados e tempestade de conexões.
    Visível ao navegar / → /demo: o indicador travava em "Desconectado" e o backend
    recebia force_stop a cada queda (estado do robô oscilando).
    Correção (padrão socket-identity-safe):
    - handlers (onopen/onmessage/onclose) só agem se wsRef.current === ws; sockets
    órfãos são ignorados.
    -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
2026-07-03 chore(deps): requirements.txt completo e fixado para deploy real
    Versões alinhadas ao src/uv.lock, cobrindo runtime da app do Pi:
    FastAPI/uvicorn[standard], OpenCV+pupil-apriltags, pyserial-asyncio,
    filterpy/scipy e pydantic.
2026-07-03 fix(firmware): alinha pinos do config.h com Testes_eletronica.ino (fonte da verdade)
    O config.h de producao usava um pinout independente que divergia da fiacao
    real (so 4 de 15 pinos batiam, com varias colisoes de papel no mesmo GPIO).
    Realinha 1:1 com o Testes_eletronica.ino:
    - Rodas: ESQ(M2)=12/14/13 DIR(M3)=27/26/25
    - Garfo (M1): 18/19/5
    - Encoder DIR: 34/35 (era 14/23); ESQ 32/33 e I2C 21/22 ja corretos
    Desabilita os fim-de-curso (-1): robo ainda sem chaves montadas.
    Documenta cuidados de hardware herdados: GPIO 12 strapping pin (LOW no boot)
    e GPIO 34/35 input-only (exigem pull-up externo).
    [config.h, motors.cpp]
2026-07-03 fix(nav): adiciona fase COARSE_ALIGN para evitar oscilação com heading > 45°
    Quando o robô inicia a navegação quase perpendicular à tag (|pitch| > 45°),
    o controlador antigo recalculava omega a cada frame. Isso causava ciclo-limite:
    pequenas rotações alteravam a leitura da câmera e flipavam o sinal do comando,
    fazendo as rodas oscilar rapidamente sem o robô convergir.
    Solução: nova fase COARSE_ALIGN gira com omega FIXO (2 rad/s, direção
    determinada pelo sinal do pitch na entrada) até |pitch| < 35° (histerese).
    Só então transita para APPROACH normal.
    [test_navigation.py]
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2026-07-03 feat(imu): calibração de bias (zero-rate) do giroscópio
    O bias de taxa-zero do MPU-6050 fazia o heading do EKF derivar com o robô
    parado (maior fonte de erro de heading real). GyroCalibrator amostra gz com o
    robô comprovadamente parado (setpoint zero e encoders ~0), trava o bias na
    média e rastreia drift térmico via EMA lenta. serial_loop passa gz cru pelo
    calibrador (sign*(gz-bias)) antes do EKF. Config expõe sinal do eixo e limiares.
    [config.py, state.py, test_gyro_calibration.py]
2026-07-03 feat(imu,vision): auto-orientação do IMU pela gravidade + calibração real da câmera
    - GyroCalibrator agora auto-detecta o eixo de yaw e o sinal pela gravidade na
    partida (sem teste de giro manual); projeta o giroscópio na vertical real,
    mede inclinação da placa e mantém rastreio de bias/drift térmico.
    - config: IMU_AUTO_ORIENT + IMU_TILT_WARN_DEG; serial_loop passa (gyro, accel).
    - câmera: intrínsecos reais (OpenCV, 28 fotos 640x480, reproj 0.144 px); .env e
    docs ajustados para 640x480.
    - docs: plano de teste no robô real; script bench_setpoint.
    [bench_setpoint.py, config.py, state.py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]
2026-07-03 fix(firmware): compila no Pi — LOW->0 em config.h e default_envs=esp32dev
    config.h usava o macro Arduino LOW, mas pid.cpp inclui config.h sem
    Arduino.h — primeiro pio run real quebrou. FORK_LIMIT_ACTIVE_LEVEL agora
    é 0 literal (LOW), header independente de macros.
    pio run sem argumento compilava também o env esp32_test (só protocol.cpp,
    sem setup/loop) e falhava no link. default_envs=esp32dev restringe run/upload
    ao firmware do robô; esp32_test fica para pio test. Platform do env de teste
    fixada em @^6.0.0 (Core 2.x, API LEDC por canal).
    [config.h]
2026-07-03 feat(pi): backend serve o frontend buildado — modo operação sem Node no Pi
    Se frontend/dist/ existir, main.py monta os estáticos na porta 8000 com
    fallback SPA (BrowserRouter: refresh em /map e /demo devolve o app; o
    StaticFiles do Starlette sinaliza 404 com HTTPException, daí o try/except).
    Rotas da API e /ws têm precedência — o mount vai por último.
    Fluxo de operação: npm run build no Mac -> rsync dist/ para o Pi -> celular
    abre http://<IP_DO_PI>:8000/ (mesma origem, WebSocket resolve sem
    VITE_PI_WS_URL). Validado ao vivo: /, /map, /demo, /maps/current e /ws na
    mesma porta; 179 testes verdes.
    Plano de testes e .env.example atualizados com as duas topologias
    (DEV: vite no Mac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
    [main.py]
2026-07-06 fix(firmware): auto-recuperação do MPU-6050 + checklist de medições no config.h
    O wake do MPU era enviado uma única vez no setup(), sem verificação: se o
    write I2C falhasse (mau contato no instante do boot), o sensor ficava em
    sleep reportando zeros até o próximo power-cycle — falha observada na
    bancada. readMpu() agora sinaliza leitura morta (I2C incompleto ou tudo
    zero, impossível com o acelerômetro vivo) e, após ~1 s de leituras mortas,
    o loop reenvia o comando de wake.
    config.h ganha o bloco de MEDIÇÕES PENDENTES (o que medir, como, unidade e
    onde gravar) para o bring-up no robô.
    [config.h, main.cpp]
2026-07-06 Corrige sinais de giro (manual e visão) e atualiza docs pós-bancada
    Bancada 2026-07-06:
    - joystick_to_twist: omega = -x — joystick à direita agora vira à direita
    (convenção do projeto: omega positivo = anti-horário; o manual virava
    invertido). Teste test_joystick_full_right atualizado para a convenção.
    - pose.py: nega o x do frame óptico OpenCV (positivo = direita) na fronteira
    para a convenção do projeto/simulador (x_cm positivo = tag à esquerda);
    sem isso a navegação autônoma viraria para longe da tag.
    - Docs sincronizados com o hardware validado: encoders ESQ=23/15 (x4,
    PPR=1440), canais de motor remapeados (ESQ=27/26/25, DIR=12/14/13),
    MPU com az negativo (z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
    [test_kinematics.py]
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2026-07-07 Limpa plano de teste (espinha única) + reconcilia tamanho da tag nos mapas
    - real-robot-test-plan.md: remove a Trilha A/B "sem encoder" (encoder OK),
    deixando Fase 0→1→2→3 como caminho único; move o .env para a Fase 0 (antes
    da câmera); corrige o default do DOCK_PITCH_TO_TAG_YAW_OFFSET_RAD (0.0 = real,
    não π) e o check de tamanho de tag.
    - maps/*.json: tag_size_m 0.05 -> 0.04 (tag real medida = 4 cm), agora consistente
    com config.APRILTAG_SIZE_CM e o default do detector (era só metadata, não afeta
    detecção nem testes).
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2026-07-07 Visão: compensação da câmera inclinada (CAMERA_TILT_DEG) + fix do x no EKF
    A câmera fica no topo do trilho do garfo olhando para baixo (nivelada ela
    não vê tags de perto: FOV vertical ~34°, tag só entra no quadro além de
    ~3,3×desnível). Mas o z do AprilTag é medido no EIXO ÓPTICO (hipotenusa):
    sem compensação, +66% de erro a 15 cm com 20 cm de desnível — exatamente no
    standoff de parada.
    - config: CAMERA_TILT_DEG (default 0 = comportamento atual) com o
    procedimento de medição (tilt = atan(Δh/d)) e o aviso de recalibrar o
    CAMERA_TO_FORK_OFFSET_CM depois (offset sem tilt absorve a hipotenusa).
    - pose.py: _camera_to_level() rotaciona pose_t/pose_R por -tilt em torno d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
    [config.py, test_hardware_interfaces.py]
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2026-07-07 Backend: câmera da navegação também força a resolução da calibração
    Mesma armadilha corrigida no teste_cam agora fechada no caminho REAL
    (CameraVisionSource): a resolução da calibração (image_size do JSON) tem
    prioridade sobre config/env, com warning quando divergem. Se a câmera não
    aceitar a resolução da calibração: RuntimeError com REQUIRE_CAMERA_
    CALIBRATION=1 (padrão — navegação com z/x inválidos é pior que não subir),
    ou error no log com =0. Helper calibration_image_size() compartilhado em
    vision/calibration.py; teste_cam passa a usá-lo.
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2026-07-07 Teste de observações fixa tilt=0 (valida a negação do x, não o tilt)
    O default calibrado CAMERA_TILT_DEG=28.4 rotacionava a pose no teste que só
    valida a convenção de sinal do x — monkeypatch para 0.
    [test_hardware_interfaces.py]
2026-07-07 Corrige sinal do offset câmera→garfo: z = distância da ponta do garfo
    A lente fica ~25,5 cm ATRÁS da ponta do garfo; pose.py SOMA o offset ao z
    lido, então offset_z deve ser NEGATIVO (-25.5). Com +25.5 o z reportado
    saía ~2x a distância real (visto na bancada 2026-07-07 — a "duplicação" do
    z no teste_cam era a leitura da lente + 25.5 somados). Após o offset, z_cm
    é a distância da PONTA DO GARFO até a tag — referência do ZREF/standoff.
    [config.py]
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2026-07-07 CAMERA_INDEX fixado em 1 no código (câmera nova = /dev/video1)
    Decisão da equipe: valor hardcoded em config.py, sem env override — o
    CAMERA_INDEX do .env deixa de ter efeito (aviso no .env.example e no
    teste_cam). Se a enumeração mudar, editar a linha no config.
    [config.py]
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2026-07-07 Visão/dock hardcoded (sem env): dock LIGADO por padrão + parâmetros fixos
    Bancada 2026-07-07: "tag perdida por tempo prolongado" imediato ao entrar
    em AUTOMATICO — o DOCK_TO_TAG vinha do env (default 0), então todo restart
    do backend caía no navegador legado, que trava por tag-loss. Decisão:
    - DOCK_TO_TAG_ENABLED = True hardcoded — dock é o modo padrão do
    AUTOMATICO-sem-missão (desligável em runtime via POST /dock/disable);
    - CAMERA_FRAME 1280x720, CAMERA_TILT_DEG 22.7 e APRILTAG_QUAD_DECIMATE 2.0
    também hardcoded — valores calibrados não dependem mais de .env.
    Teste guarda-corpo atualizado (default ligado, sem getenv).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
    [config.py, test_dock_to_tag.py]
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2026-07-07 EKF: não corrigir por tag durante o DOCK (curvas tortas/engasgo)
    Efeito colateral do fix dos april_tag_id: com as tags casando com o mapa,
    o EKF passou a receber correções DURANTE a execução do dock — e com a tag
    física fora da posição declarada no mapa (teste de bancada), cada
    avistamento teleportava a pose. O executor perseguia um alvo num frame que
    já não existia → curvas não-discretas e movimento engasgado (bancada
    2026-07-07, diferente do manual que não usa EKF).
    O dock planeja e executa no frame odométrico do instante do plano —
    consistência importa mais que precisão absoluta em trajetos curtos.
    Correções por tag continuam ativas fora do DOCKING (missão/manual)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
2026-07-07 Dock: teto de giro anti-derrapagem + plano completo visível no painel
    Bancada 2026-07-07, derrapagem/engasgo residual no dock:
    - NAV_TURN_MAX_OMEGA_RADS = 1.6: girar no lugar a 2,5 rad/s derrapa as
    rodas → odometria conta rotação que não houve → θ do EKF errado → o
    AVANÇO seguinte nasce torto e corrige em arco. Janela 1,0–1,6 rad/s =
    giro consistente (nem trava, nem derrapa).
    - NAV_MIN_V_MS 0.07→0.09: 2,6 rad/s de roda ficava na zona de stick-slip
    do PID no chão (trava-solta-trava = engasgo rítmico).
    - DockInfo.plan: rota completa na telemetria; DockPanel lista cada
    segmento numerado (GIRO x°→y° / AVANÇO n cm→(x,y)), riscando os feitos
    e destacando o atua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
    [config.py, models.py]
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2026-07-07 Visão/EKF: remontagem da câmera (tilt 30°, offset -10) + braço lente→eixo
    Medições da bancada 2026-07-07 (câmera remontada pela 2ª vez):
    - CAMERA_TILT_DEG 22.7 → 30.0 (medido pela equipe; validar z na fita).
    - CAMERA_TO_FORK_OFFSET z -13.3 → -10.0 (lente a 10 cm da ponta da garra).
    - LENS_TO_AXLE_FORWARD_CM = 18.0 novo: a correção do EKF por tag calculava
    a posição da LENTE e a tratava como pose do robô — viés sistemático de
    ~18 cm a cada avistamento, da ordem do standoff num corredor de 80 cm.
    Agora converte lente → centro (eixo das rodas) antes de corrigir.
    ASSUNÇÃO A CONFIRMAR: IMU montado no meio do eixo (medida dada foi
    lente→IMU); se não estiver,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
    [config.py]
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2026-07-09 Add files STL de modelagem da parte mecânica
    [Carretel.stl, Eixo.stl, Garfo.stl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]
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2026-07-09 Revisão da documentação: consistência com o código, correções técnicas e envs sem efeito
    - Corrige divergências doc/código: pinos PWM na tabela do bring-up, GPIO 2
    (alimentação do encoder) no troubleshooting de gravação, prioridade de
    alvos da missão (L3/R1 + seed 42 na state machine), resolução de tag por
    april_tag_id do mapa, FAULT/re-plan do dock-to-tag, fases da navegação
    legada, histórico do tilt da câmera (22,7°/28,4°/30°).
    - Marca como sem efeito os envs não lidos pelo código (MAP, CAMERA_INDEX,
    CAMERA_FRAME_*, MISSION_SEED) no .env.example e config.py.
    - Atualiza contagens de teste (210 pytest: 209 passam, 1 pulado; 11 vitest)
    e contagens por mó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
    [config.py]
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
